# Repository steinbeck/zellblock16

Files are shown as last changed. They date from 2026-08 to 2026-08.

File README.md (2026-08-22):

# Zellblock 16

**Ein selbstgebauter Traktionsakku für den Kumpan 54 ignite.**
16 LiFePO4-Zellen in Reihe, 5,38 kWh, in einem 3D-gedruckten Gehäuse, das
die drei originalen Wechselakkus ersetzt.

> [!CAUTION]
> ### Entwurf — nicht gebaut, nicht getestet, nicht abgenommen
>
> Dieses Repository beschreibt einen **Konstruktionsentwurf**, der als
> Diskussionsgrundlage im [Elektroroller-Forum](https://www.elektroroller-forum.de/)
> gedacht ist. Stand heute gilt ohne Einschränkung:
>
> - **Kein Teil wurde gefertigt.** Sämtliche Maße stammen aus Berechnung und
>   CAD, keines aus einem realen Bauteil in der Hand.
> - **Nichts wurde erprobt** — weder elektrisch noch mechanisch noch thermisch.
>   Kein Strom ist geflossen, keine Zelle wurde verspannt, kein Gehäuse hat je
>   im Akkuschacht gesteckt.
> - **Es gibt keine behördliche Abnahme.** Der Umbau berührt die
>   Betriebserlaubnis und damit den Versicherungsschutz. Eine Prüforganisation
>   war zu keinem Zeitpunkt beteiligt.
>
> Die Zahlen sind sorgfältig hergeleitet und in `grundlagen.md` mit ihrer
> Herkunft belegt — aber hergeleitet ist nicht bewiesen. Wer darauf aufbaut,
> prüft jede einzelne selbst gegen seine eigenen Bauteile und Datenblätter.
>
> **Rückmeldungen sind ausdrücklich erwünscht.** Genau dafür liegt das hier
> öffentlich.

<p align="center">
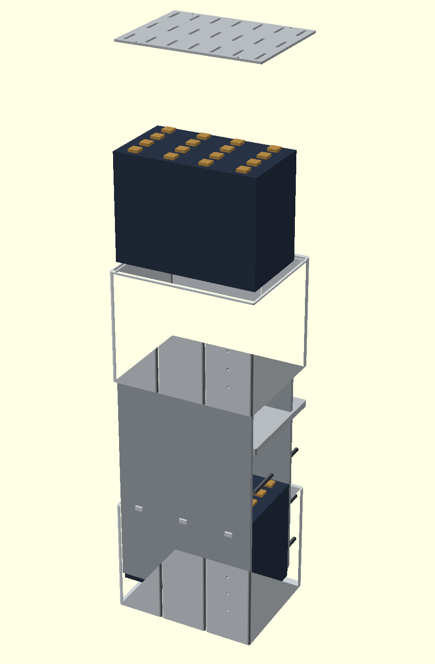
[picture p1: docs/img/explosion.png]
Explosionsdarstellung des Aufbaus
  
</p>

<p align="center">
  <a href="https://steinbeck.github.io/zellblock16/">Projektseite</a> ·
  <a href="https://steinbeck.github.io/zellblock16/blaupause.html">Explosionszeichnung</a> ·
  <a href="https://steinbeck.github.io/zellblock16/verschaltung.html">Verschaltung</a> ·
  <a href="https://steinbeck.github.io/zellblock16/verdrahtung.html">Verdrahtung</a> ·
  <a href="https://steinbeck.github.io/zellblock16/testaufbau.html">Testaufbau</a>
</p>

---

## Worum es geht

Der Kumpan 54 ignite fährt mit bis zu drei Wechselakkus vom Typ Kraftpaket 2.0.
Sie altern, zeigen Fehler, und ihr Batteriemanagement ist auf ein
Flottenmanagement-Backend ausgelegt, das nicht mehr verlässlich erreichbar ist.
Ersatz gibt es — zu **1.400 € pro Stück**.

| | Original, 3 Packs | Zellblock 16 |
|---|---:|---:|
| Preis | 4.200 € | **~1.500 €** |
| Energie | 4,33 kWh | **5,38 kWh** |
| je kWh | 970 € | **282 €** |
| Zyklen | ~1.000 | **> 6.000** |
| Ersatz einer defekten Zelle | ganzer Pack, 1.400 € | eine Zelle, **40 €** |

Am deutlichsten wird es an einem einzelnen Pack: Einer kostet 1.400 € und
liefert 1,44 kWh. Der komplette Eigenbau kostet 1.515 € und liefert 5,38 kWh —
**das 3,7-fache an Energie für 8 % mehr Geld.**

---

## Kenndaten

| | |
|---|---|
| Konfiguration | 16S1P LiFePO4 |
| Zelle | EVE LF105, 105 Ah, 3,2 V |
| Nennspannung | 51,2 V, Ladeschluss 58,4 V |
| Energie | 5,38 kWh |
| Dauerstrom / Spitze | 100 A / 180 A |
| Masse | 43,2 kg |
| Außenmaß | 430 mm hoch; Grundriss wird nach dem Ausmessen neu festgelegt |
| Reichweite, rechnerisch | ~100 km |

---

## Der Aufbau

**Metall trägt, Kunststoff hüllt.** Zwei durchgehende Aluminiumplatten über die
volle Bauhöhe, verbunden durch acht waagerechte Gewindestangen, nehmen die
Zellverspannung auf. Das gedruckte Gehäuse überträgt keine Kräfte — es ist
Hülle, Führung im Schacht und Isolierung gegen den Rahmen.

Die Zellen stehen in **zwei Etagen zu je acht**, angeordnet als zwei Stapel von
vier. Sie quellen über ihre Lebensdauer in Dickenrichtung auf und werden deshalb
mit **3–5 kN je Stapel** vorgespannt; am Lebensende entwickeln sie bis zu 30 kN.

### Drei Zahlen, an denen die Konstruktion hängt

**Die Außenkontur ist keine Erfindung, sondern eine Ableitung.** Sie ist die
Vereinigungsmenge der drei Original-Fachgrundrisse — 90 × 215 mm mit 5 mm
Eckradius, dreimal nebeneinander. Wo zwei Fächer aneinanderstoßen, treffen an
Vorder- und Rückkante zwei Viertelrundungen aufeinander, und dazwischen bleibt
eine Einbuchtung stehen. Genau dort greifen die Führungsrippen des Schachts ein.
**Diese Nuten entstehen von selbst; sie werden nicht konstruiert.** Deshalb passt
die Kontur per Konstruktion, und am Fahrzeug muss nichts gefräst werden.

**Die Höhenbilanz geht mit 425 von 430 mm auf** — aber nur, weil die
Zwischenplatte die 5 mm überstehenden Zellpole samt Busbars und Muttern in
Kanälen aufnimmt, statt sie obendrauf zu addieren. Naiv gerechnet wären es
436 mm, und das Projekt wäre gescheitert.

**In der Breite bleiben 1,7 mm Spiel je Seite** bei einer Drucktoleranz von
±0,4 mm. Deshalb geht dem Vollteil ein Testring voraus.

---

## Dokumente

| Datei | Inhalt |
|---|---|
| [`grundlagen.md`](grundlagen.md) | Faktenbasis. **Jede Zahl trägt eine Herkunftsmarke** — Herstellerdokument, Messung, Berechnung, Recherche oder offener Punkt. |
| [`konstruktion.md`](konstruktion.md) | Konstruktionsspezifikation: Zellen, Anordnung, Skelett, Kräfte, Gehäuse, Elektrik, Montagereihenfolge |
| [`kosten.md`](kosten.md) | Kostenabschätzung, brutto, mit wahrscheinlichem Wert |
| [`einkaufsliste.md`](einkaufsliste.md) | Was für den Funktionstest zu beschaffen ist |
| [`messprotokoll.md`](messprotokoll.md) | Was am Fahrzeug noch zu messen ist |
| [`cad/`](cad/) | Parametrisches OpenSCAD-Modell |
| `blaupause.html`, `verschaltung.html`, `verdrahtung.html`, `testaufbau.html` | Zeichnungen — Explosionsdarstellung, Zellverschaltung, Stromlaufplan, Testaufbau |
| [`spezifikation.md`](spezifikation.md) | Erster Entwurf, **veraltet** — enthält an neun Stellen widerlegte Werte und bleibt nur als Diskussionsverlauf erhalten |

Die Belegmarken in `grundlagen.md` sind der Kern der Dokumentation. Der erste
Entwurf scheiterte daran, dass abgeleitete Forenzahlen und belegte
Herstellerangaben ununterscheidbar nebeneinanderstanden — ein aus einer
ungenauen Anzeige geschätzter Spitzenstrom von 240 A schlug unbemerkt bis in
eine Lieferantenanfrage durch. Der belegte Wert liegt bei 180 A.

---

## CAD

```sh
cd cad
openscad -o testring.stl --export-format binstl testring.scad
openscad -D 'teil="unten"' -o segment_unten.stl --export-format binstl gehaeuse.scad
```

Alle Maße stehen ausschließlich in [`cad/parameter.scad`](cad/parameter.scad).
Ändert sich eines, pflanzt es sich durch alle Teile fort. `assert`-Prüfungen
brechen ab, wenn eine Änderung die Konstruktion unmöglich macht — etwa wenn das
Spiel in der Breite unter die doppelte Drucktoleranz fällt oder die Stirnwand so
dünn wird, dass die Zwickelnut sie durchbricht.

| Teil | Material | Druckzeit |
|---|---:|---:|
| Segment unten | 1,53 kg | ~14,8 h |
| Segment oben | 1,17 kg | ~11,3 h |
| Zwischenplatte | 0,45 kg | ~4,4 h |
| Deckel | 0,20 kg | ~1,9 h |
| **Gesamt** | **3,36 kg** | **~32 h** |

Werkstoff ASA wegen der Sommertemperaturen im Akkuschacht; für den Testring
genügt PETG. Gedruckt auf einem BambuLab H2S — dessen Bauhöhe von 340 mm ist der
Grund für die Zweiteilung des Gehäuses.

---

## Stand

- [x] Faktenbasis aus dem Herstellerdokument
- [x] Zellwahl und Anordnung
- [x] Gehäuse, Zwischenplatte, Deckel als parametrisches Modell
- [x] Testring gedruckt — **passt nicht, Ursache gefunden**
- [ ] **Schacht nach Entfernen der Separationsrippen ausmessen** ← hier steht das Projekt
- [ ] Außenkontur auf Quaderform umstellen, zweiter Testring
- [ ] Zellen und BMS bestellen — siehe [`einkaufsliste.md`](einkaufsliste.md)
- [ ] **Funktionstest außerhalb des Fahrzeugs**, ohne Gehäuse
- [ ] Probefahrt im provisorischen Gehäuse
- [ ] Erst danach: Bodenkontakte ausbauen, Rippen entfernen *(unumkehrbar)*
- [ ] Endgültiges Gehäuse drucken und einbauen
- [ ] Abnahme durch eine Prüforganisation

### Was der Testring ergeben hat

Er passt nicht — und hat damit genau geleistet, wofür er gebaut wurde: **zwei
Stunden Druckzeit statt 32 Stunden und 3,4 kg** beim Vollteil, und der Fehler
wäre sonst erst beim Zusammenbau mit verspanntem Zellstapel aufgefallen.

Die Ursache saß in einer Grundannahme. Ich war davon ausgegangen, dass zwei
Führungsrippen in die **Rundungszwickel** zwischen den Akkus greifen, und hatte
die gesamte Außenkontur darauf aufgebaut. Tatsächlich stehen die Rippen **10 mm**
vor — in einen Zwickel von 5 mm Tiefe passt das nicht. Die Akkus stehen also mit
echtem Spalt nebeneinander, der Schacht ist breiter als angenommen, und die
Nuten sitzen an der falschen Stelle.

**Die Lösung vereinfacht die Konstruktion:** Die beiden Separationsrippen werden
entfernt, die Außenkontur wird ein schlichter Quader statt einer Vereinigung
dreier Fachgrundrisse, und die Stirnwand darf von 8 auf 5 mm dünner werden.

---

## Sicherheit

Es wird mit **58,4 V DC** und Kurzschlussströmen im Kiloampere-Bereich
gearbeitet, an einem Paket von 43 kg. Lithiumzellen können bei Fehlbehandlung in
Brand geraten.

Dieses Repository ist **keine Bauanleitung**, sondern ein unerprobter Entwurf
für ein konkretes Fahrzeug — siehe die Warnung ganz oben. Wer Vergleichbares
vorhat, prüft jede Zahl selbst gegen seine eigenen Bauteile und Datenblätter.

Der Umbau berührt **Betriebserlaubnis und Versicherungsschutz**. Vor der
Nutzung im öffentlichen Straßenverkehr ist eine Prüforganisation einzuschalten.

---

## Dank

An **Raffler** aus dem Elektroroller-Forum für das CAN-Modul, das den
Motorcontroller ohne das originale Batteriemanagement freigibt, und für
Auskünfte, die kein Handbuch enthält: dass alle drei Anschlüsse parallel liegen,
dass jeder 100 A trägt, und dass der Roller über die Datenpins prüft, ob ein
Stromkreis geschlossen ist.

An **JJac**, dessen dokumentierter Umbau an einem 54 Ri zeigte, dass der Weg
überhaupt gangbar ist.

---

## Lizenz

**[CERN Open Hardware Licence Version 2 — Strongly Reciprocal](LICENSE)**
(`CERN-OHL-S-2.0`), Copyright 2026 Christoph Steinbeck.

Die CERN-OHL wurde für genau diesen Fall geschrieben: Sie deckt
**Konstruktionsunterlagen, CAD-Dateien und daraus gefertigte Produkte** ab, wo
Software- und Textlizenzen nur den Quelltext oder den Text erfassen.

Was das praktisch heißt:

- **Nachbauen, ändern, weitergeben ist ausdrücklich erwünscht.**
- Wer den Entwurf verändert und **weitergibt** — als Dateien oder als gebautes
  Gerät —, muss die geänderten Unterlagen unter derselben Lizenz zugänglich
  machen. Verbesserungen fließen so zurück.
- Wer für sich baut und nichts weitergibt, hat keinerlei Pflichten.
- Es gibt **keinerlei Gewährleistung**. Siehe die Warnung am Anfang: Dieser
  Entwurf ist ungebaut und ungeprüft.

Ausgenommen ist das Benutzerhandbuch des Fahrzeugs. Es ist urheberrechtlich
geschütztes Herstellermaterial, gehört nicht zu diesem Repository und wird hier
nur mit Seitenzahlen zitiert.

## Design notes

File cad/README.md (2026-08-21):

# CAD — Zellblock 16

Parametrisches Modell. Alle Maße stehen ausschließlich in
`parameter.scad`; ändert sich eines, pflanzt es sich durch alle Teile
fort. **Nie Maße in die Geometriedateien schreiben.**

## Dateien

| Datei | Inhalt |
|---|---|
| `parameter.scad` | sämtliche Maße, abgeleitete Größen, Plausibilitätsprüfungen |
| `kontur.scad` | Außen- und Innenkontur, Zellraster |
| `testring.scad` | Musterstück T-01 für den Passungstest |
| `gehaeuse.scad` | die beiden Gehäusesegmente |
| `platten.scad` | Zwischenplatte und Deckel |

## Bauen

```sh
openscad -o testring.stl --export-format binstl testring.scad
```

**Die STL-Dateien liegen nicht im Repository.** Sie sind Erzeugnisse aus
den `.scad`-Quellen und würden bei jeder Parameteränderung veralten, ohne
dass es auffiele — und das Projekt ist gerade in Änderung: Der Testring
kann eine Maßkorrektur auslösen, die alle vier Teile betrifft. Einzige
Quelle der Wahrheit sind die `.scad`-Dateien.

Alle Teile auf einmal:

```sh
for t in unten oben; do
  openscad -D "teil=\"$t\"" -o segment_$t.stl --export-format binstl gehaeuse.scad
done
for t in zwischen deckel; do
  openscad -D "teil=\"$t\"" -o $t.stl --export-format binstl platten.scad
done
openscad -o testring.stl --export-format binstl testring.scad
```

Die Echo-Ausgabe listet die abgeleiteten Maße. Die `assert`-Prüfungen in
`parameter.scad` brechen ab, wenn eine Maßänderung die Konstruktion
unmöglich macht — etwa wenn das Spiel in der Breite unter die doppelte
Drucktoleranz fällt oder die Stirnwand die Zwickelnut nicht mehr trägt.

## Zur Außenkontur

Sie ist die **Vereinigungsmenge dreier Originalfach-Grundrisse**, nicht
ein Quader mit angesetzten Nuten. Wo zwei Fächer aneinanderstoßen,
treffen an Vorder- und Rückkante zwei Viertelrundungen aufeinander;
dazwischen bleibt eine linsenförmige Einbuchtung von 2 × 5 mm Breite und
5 mm Tiefe stehen. Das ist die Zwickelnut, in die die Führungsrippe des
Schachts greift. **Sie entsteht von selbst — sie wird nicht
konstruiert.** Damit passt die Kontur per Konstruktion, und am Fahrzeug
muss nichts gefräst werden.

## Testring T-01

Vor der Vollausführung verbindlich. Er prüft in einem Zug:

1. **Passung der Außenkontur** in den Akkuschacht
2. **Eingriff der Führungsrippen** in die vier Zwickelnuten
3. **Innenmaß** gegen zwei echte Zellen — die beiden 2 mm hohen Stege
   innen markieren den Sollplatz des Zellblocks

Dazu Höhenmarken alle 10 mm an der linken Außenwand: Klemmt der Ring,
lässt sich daran ablesen, wie tief er kam.

| | |
|---|---|
| Material | **PETG genügt** — der Ring wird nicht heiß und trägt nichts. ASA erst beim Vollteil. |
| Volumen | ~210 cm³, also rund 225 g |
| Druckzeit | **4–6 h** mit 0,4 mm Düse, 3–4 h mit 0,6 mm |
| Orientierung | stehend, Unterseite auf der Platte |

Die Unterseite bleibt bewusst plan: Nur so lässt sich mit einer
Fühlerlehre feststellen, ob der Ring wirklich auf dem Schachtboden
aufsitzt und nicht irgendwo hängt.

**Warum der Aufwand:** In der Breite bleiben 1,7 mm Spiel je Seite bei
einer erwarteten Drucktoleranz von ±0,4 mm. Ein Fehldruck des Vollteils
kostet 3 kg Material und über 30 Stunden.

## Gehäusesegmente

```sh
openscad -D 'teil="unten"' -o segment_unten.stl --export-format binstl gehaeuse.scad
openscad -D 'teil="oben"'  -o segment_oben.stl  --export-format binstl gehaeuse.scad
```

| | Unterteil | Oberteil |
|---|---:|---:|
| Eingebaute Höhe | 213,5 mm | 207,5 mm |
| Druckhöhe | 221,5 mm¹ | 207,5 mm |
| Material | 1,53 kg | 1,17 kg |
| Durchbrüche | 3 Kabel, 8 Schrauben | 18 Lüftung, 8 Schrauben |

¹ inklusive der überstehenden Zentrierzapfen. Beide liegen unter der
Bauhöhe des H2S von 340 mm; ein `assert` prüft das.

**Zusammen 2,7 kg**, dazu kommen Zwischenplatte und Deckel.

### Wie die Segmente zusammenhalten

**Nicht miteinander** — jedes wird für sich an die **durchgehende hintere
Aluplatte** geschraubt, die mit 400 mm Höhe über die Trennfuge reicht.
Vier Schrauben je Segment durch die 8 mm starke Rückwand in Gewinde im
Aluminium. Die sechs Zentrierzapfen sorgen nur für Flucht beim
Zusammensetzen, sie tragen nichts.

Das ist derselbe Grundsatz wie beim Rest der Konstruktion: Metall trägt,
Kunststoff hüllt.

### Warum es keine Führungsnuten für die Endplatten gibt

Zwischen Seitenwand und Zellblock bleiben nur **2,2 mm**. Eine Nut oder
Führungsrippe bräuchte mehr, und die Seitenwand ist mit 2,5 mm ohnehin am
Limit. Gebraucht werden sie auch nicht: Die hintere Platte liegt flach an
der Rückwand an und ist damit von selbst positioniert; die vordere steht
beim Einbau auf zwei Nasen im Boden und wird anschließend von den
Zugstangen gehalten.

### Warum der Boden nicht verrippt ist

Er liegt vollflächig auf dem Schachtboden auf und kann sich deshalb gar
nicht durchbiegen — er muss die Last nur durchleiten, nicht auf Biegung
aufnehmen. Rippen würden hier bloß die Zellen anheben, statt sie auf dem
Boden stehen zu lassen. Die drei Kabeldurchführungen liegen im hinteren
Bereich beim BMS, wo keine Zellmasse darauf steht.

### Lüftung

216 mm² in den Stirnwänden des Kopfraums. Das ist wenig, aber der
Kopfraum misst nur 12 mm, und thermisch ist es unkritisch: 24 W
Verlustleistung ergeben rund 9 K Übertemperatur, abgeführt über die
Gehäuseoberfläche. Die Schlitze sind vor allem ein Zugeständnis an die
Datenblattwarnung, die Zellen nicht einzukapseln. Die Hauptöffnung trägt
später der Deckel.

## Zwischenplatte und Deckel

```sh
openscad -D 'teil="zwischen"' -o zwischen.stl --export-format binstl platten.scad
openscad -D 'teil="deckel"'   -o deckel.stl   --export-format binstl platten.scad
```

**Die Zwischenplatte ist das Bauteil, an dem die Höhenbilanz hängt.** Sie
sitzt auf den Zellgehäusen der unteren Etage auf und nimmt deren 5 mm
überstehende Pole samt Busbars und Muttern in vier Längskanälen auf,
statt sie obendrauf zu addieren. Ohne diesen Kunstgriff käme der Aufbau
auf 436 statt 425 mm und wäre gescheitert.

Die Kanäle liegen unter den vier Polspalten bei x = 36,4 / 103,4 /
166,7 / 233,7 mm. Dazwischen bleiben 35–39 mm massives Material stehen —
die Platte wird also nicht in Streifen zerlegt. Über den Kanälen tragen
3 mm, ein `assert` prüft das.

Der Deckel trägt die eigentliche Lüftung: **3.570 mm²** gegen 216 mm² in
den Stirnwänden des Kopfraums, wo bei 12 mm Bauhöhe kaum Platz war.

## Materialbedarf und Druckzeit

| Teil | Volumen | Masse |
|---|---:|---:|
| Segment unten | 1.432 cm³ | 1,53 kg |
| Segment oben | 1.093 cm³ | 1,17 kg |
| Zwischenplatte | 423 cm³ | 0,45 kg |
| Deckel | 188 cm³ | 0,20 kg |
| **Gesamt** | **3.136 cm³** | **3,36 kg** |

**Zur Druckzeit.** Der Testring lieferte den Messwert: 210 cm³ in
2 h 10 min im Standardprofil, also **97 cm³/h**.

| Teil | Druckzeit |
|---|---:|
| Segment unten | ~14,8 h |
| Segment oben | ~11,3 h |
| Zwischenplatte | ~4,4 h |
| Deckel | ~1,9 h |
| **Gesamt** | **~32 h** |

Vier Einzeldrucke, der längste knapp fünfzehn Stunden. Die
0,4-mm-Standarddüse genügt; eine 0,6er würde halbieren, wird aber nicht
gebraucht.

> Ein erster Anlauf mit einem hohen Qualitätsprofil brauchte 7 h 45 für
> denselben Ring, was auf 116 h für das Gehäuse hochgerechnet hätte. Für
> die **Maßhaltigkeit** ist das Profil weitgehend gleichgültig: Ob der
> Ring mit 1,7 mm Spiel je Seite passt, hängt an Flusskalibrierung und
> Materialschrumpf, nicht an der Schichthöhe.

## Rückmeldung nach dem Test

Passt der Ring, geht es an die Gehäusesegmente. Klemmt er, bitte melden
**wo** — an den Seitenwänden, an den Zwickeln oder an den Ecken. Danach
wird in `parameter.scad` genau eine Zahl geändert.

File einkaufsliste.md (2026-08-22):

# Einkaufsliste — Funktionstest

**Stand:** 2026-08-22
**Zweck:** Alles für Schritt 1 bis 4 der Vorgehensreihenfolge
(`grundlagen.md` §8.6) — Pack außerhalb des Fahrzeugs aufbauen, anschließen und
am aufgebockten Roller erproben.

> [!CAUTION]
> **Sicherung, Trennschalter und Multimeter sind kein Zubehör.** Ein 16S-Pack
> liefert Kurzschlussströme im Kiloampere-Bereich; ein vergessener Schraubschlüssel
> auf zwei Polen verdampft Metall. Wer ohne diese drei Positionen anfängt, baut
> ohne Bremse.

---

## Bemerkenswert vorab

**Der Testkauf ist fast der gesamte Materialbedarf.** Es fehlen anschließend nur
noch Aluminium-Endplatten (~115 €) und Filament (~110 €). Der Grund: Die Zellen
dominieren die Rechnung, und sie werden vollständig gebraucht — ein reduzierter
Testkauf ist nicht sinnvoll, weil alle sechzehn Zellen aus derselben Charge
stammen müssen (`grundlagen.md` §8.6).

---

## A · Zwingend

| Pos | Artikel | Menge | Preis | Anmerkung |
|---|---|---:|---:|---|
| A1 | **EVE LF105**, 105 Ah, 3,2 V, Grade A | 16 | **640 €** | **eine Bestellung, eine Charge.** 39,98 € brutto je Stück — die 33,60 € im Shop sind der PV-Nullsteuersatz und gelten hier nicht |
| A1b | **CAN-Modul Raffler**, Hardware + **Batteriesimulation** | 1 | **270 CHF** ≈ 285 € | **Ohne Batteriesimulation gibt der Controller nicht frei.** Muss vor dem Testlauf vorliegen. Kontakt: Telegram `t.me/raffler5` |
| A2 | **BMS JK PB2A16S20P**, 16S, 200 A, 2 A aktiver Balancer | 1 | **109 €** | Softwareversion **≥ 6.0** verlangen. Ein RS485-Port bleibt für Rafflers Modul frei |
| A3a | **Busbars kurz**, M6, Lochabstand = **Zellteilung 36,35 mm** | 14 | 42–70 € | 12 gebraucht, 2 Reserve. **Liegen den Zellen nicht bei** |
| A3b | **Verbinder lang oder flexibel**, M6, **Lochabstand 63 mm** | 3 | 15–25 € | 2 gebraucht für den Übergang zwischen den Zellreihen, 1 Reserve |
| A3c | **Kabel für den Etagenübergang**, 35 mm², ~120 mm, beidseitig M6-Kabelschuh | 1 | 8–15 € | verbindet Etage 1 und 2 durch die Zwischenplatte |
| A4 | **Hauptsicherung** ANL/Mega **200 A träge** mit Halter | 1 | 25–35 € | direkt an den Pluspol des Packs |
| A5 | **Batterie-Trennschalter** ≥ 250 A | 1 | 25–45 € | erlaubt spannungsfreies Arbeiten zwischen den Versuchen |
| A6 | **Leistungskabel** 35 mm², schwarz und rot | je 2,5 m | 45–70 € | vom Pack zu den Portleitungen im Schacht |
| A7 | **Kabelschuhe** M6 und M8 für 35 mm² | 10 | 12–20 € | fertig gecrimpte Kabel sind eine Alternative zur Crimpzange |
| A8 | **Multimeter** mit 60-V-DC-Bereich | 1 | 25–60 € | Zellprüfung, Verschaltungskontrolle vor dem ersten Einschalten |
| A9 | **Drehmomentschlüssel** 2–10 Nm | 1 | 30–60 € | **Pole mit 4–6 Nm.** Gewinde sitzen im Aluminium des Zelldeckels |
| | **Summe A** | | **1.261–1.464 €** | |

## B · Provisorische Verspannung

Die Zellen müssen auch beim Test verspannt sein — 3 bis 5 kN je Stapel, sonst
quellen sie auf und nehmen Schaden (`grundlagen.md` §3.3).

| Pos | Artikel | Menge | Preis | Anmerkung |
|---|---|---:|---:|---|
| B1 | Multiplex oder Siebdruckplatte, 18–21 mm | **4** Stück ~300 × 220 mm | 25–40 € | Endplatten, **zwei Blöcke zu acht Zellen** |
| B2 | Gewindestangen M8, verzinkt | **8** × 400 mm | 15–22 € | vier je Block; für den Test genügt Baumarktqualität |
| B3 | Muttern M8 selbstsichernd, Karosseriescheiben | je 16 | 10–15 € | |
| B4 | **Tellerfedern** für M8, ~1.000 N je Stück | 48 | 30–60 € | 6 je Zugstange; halten die Vorspannung und nehmen die Alterungsdehnung auf |
| | **Summe B** | | **80–137 €** | |

> [!IMPORTANT]
> **Die Federn sind kein Zubehör, sondern Voraussetzung.** Die Zellen dehnen
> sich über die Lebensdauer um 0,7–1,5 mm je Stapel. Gegen starre Zugstangen
> ergäbe das rechnerisch über 200 kN — die Zelle nimmt bereits ab 9 kN Schaden.
> Die Federn halten die Vorspannung von 3–5 kN und begrenzen ihren Anstieg auf
> etwa 1,5 kN.
>
> Aufbau je Stange: **drei Paare** — jeweils zwei Federn gleichsinnig
> ineinander für die Kraft, die Paare wechselsinnig gestapelt für den Weg.
>
> **Auch im Testaufbau verwenden.** Die Zellen atmen bei jedem Ladezyklus: schon
> an einer neuen Zelle steigt die Kraft bei starrer Einspannung um bis zu 3 kN.
> Ohne Federn läge man bei 6–7 kN und damit knapp unter der Schadensgrenze — mit
> ihnen bei rund 5 kN. Siehe `testaufbau.html`.

## C · Laden

| Pos | Artikel | Menge | Preis | Anmerkung |
|---|---|---:|---:|---|
| C1 | **Ladegerät CC/CV, 15–20 A, Ausgangsspannung einstellbar 53–58,4 V** | 1 | 170–280 € | siehe Kasten |
| | **Summe C** | | **170–280 €** | Preise streuen stark, hier lohnt ein Vergleich |

> [!IMPORTANT]
> **Die Spannung muss einstellbar sein.** Christoph wohnt auf 800 m; jede Fahrt
> beginnt bergab, und ohne Rekuperation geht die gesamte Lageenergie in die
> Bremsen. Der Pack wird deshalb nur auf **rund 85 %** geladen — einerseits, um
> später Platz für Rekuperation zu lassen, andererseits weil ein LFP-Pack, der
> nicht bis 3,65 V geladen wird, deutlich mehr Zyklen hält.
>
> Ein fest auf 58,4 V eingestelltes Gerät kann das nicht. Für 85 % sind rund
> **54,0 V** einzustellen; die genaue Zuordnung von Spannung zu Ladestand ist bei
> LFP wegen der flachen Kennlinie ohnehin nur ungefähr (`grundlagen.md` §8.2).
>
> **Nicht das Seriengerät verwenden:** dessen 59 V liegen über dem
> LFP-Ladeschluss, und mit 6 A bräuchte es 15 Stunden.

## D · Kleinmaterial

| Pos | Artikel | Preis | Anmerkung |
|---|---|---:|---|
| D1 | Schrumpfschlauch, Isolierband, Kabelbinder | 15–25 € | |
| D2 | Isoliermatte oder Gummimatte als Unterlage | 10–20 € | Pack steht auf dem Werkstattboden |
| D3 | Aderendhülsen und Kabel für die Balancerleitungen | 10–15 € | meist liegt ein Satz beim BMS |
| | **Summe D** | **35–60 €** | |

---

## Gesamt

| Block | von | bis |
|---|---:|---:|
| A Zwingend | 1.261 € | 1.464 € |
| B Verspannung und Federn | 80 € | 137 € |
| C Laden | 170 € | 280 € |
| D Kleinmaterial | 35 € | 60 € |
| **Summe** | **1.546 €** | **1.941 €** |

Davon sind rund **1.030 €** durch konkrete Angebote belegt (Zellen, BMS und
CAN-Modul), der Rest ist geschätzt. Wer Multimeter und Drehmomentschlüssel bereits besitzt, spart
55–120 €.

**Später folgen** nur noch Aluminium-Endplatten (~115 €) und Filament (~110 €),
zusammen rund 225 €.

---

## Was bewusst nicht auf der Liste steht

| Posten | warum später |
|---|---|
| Aluminium-Endplatten | erst für das endgültige Gehäuse; beim Test tun es Holzplatten |
| Filament | die Kontur steht erst nach dem Ausmessen des Schachts fest |
| Vorladewiderstand | nötig vor der ersten Fahrt, nicht für den Aufbau |
| Crimpzange 35 mm² | vermeidbar durch fertig konfektionierte Kabel |
| CAN-Adapter, 30–60 € | kein Teil des Packs — aber **vor dem Umbau** sinnvoll, solange die Originalakkus noch laufen (`grundlagen.md` §8.5) |

---

## Reihenfolge beim Aufbau

1. **Alle 16 Zellen einzeln auf Ruhespannung messen** und notieren. Abweichungen
   über 50 mV zwischen den Zellen vor dem Verschalten klären.
2. Zellen zwischen die Platten setzen, Zugstangen **über Kreuz** anziehen.
3. **Zellen abwechselnd um 180° drehen**, direkt aneinander. Nur so liegen die
   zu verbindenden Pole übereinander (`verschaltung.html`).
4. Verschalten — **Reihenfolge und Polarität zweimal prüfen**, bevor der letzte
   Busbar gesetzt wird. Ein falsch gesetzter Verbinder bedeutet Kurzschluss über
   zwei Zellen. Je Etage sechs kurze Verbinder, **einer lang** für den Übergang
   zwischen den Zellreihen.
5. Balancerleitungen anschließen, dabei **von Zelle 1 aufsteigend**. Am BMS
   erst anstecken, wenn alle Abgriffe sitzen und die Spannungsfolge stimmt.
6. Gesamtspannung messen: bei halb geladenen Zellen **rund 52 V** erwartbar.
7. Erst dann Sicherung einsetzen und Trennschalter schließen.

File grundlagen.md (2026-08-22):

# Grundlagen: Ersatzakku Kumpan 54 ignite

**Stand:** 2026-08-20
**Status:** Verbindliche Arbeitsgrundlage. Ersetzt `spezifikation.md` (veraltet, siehe dort).
**Projektziel:** Ersatz der drei Kraftpaket-2.0-Wechselakkus durch einen fest
verbauten Eigenbau-Pack mit teilweise 3D-gedrucktem Gehäuse.

> **Sicherheitshinweis.** Es wird mit bis zu 59 V DC und Kurzschlussströmen im
> Bereich mehrerer hundert Ampere gearbeitet. Isoliertes Werkzeug verwenden,
> während der Montage stets einen Pol getrennt halten, Zellen gegen Verrutschen
> und gegen Kurzschluss zum Rahmen isolieren. Der Umbau berührt Betriebserlaubnis
> und Versicherungsschutz (Abschnitt 8).

---

## 0. Belegstatus — Legende

Jede Zahl in diesem Dokument trägt eine Herkunftsmarke. Ohne Marke gilt eine
Aussage als unbelegt und darf nicht als Planungsgrundlage dienen.

| Marke | Bedeutung |
|---|---|
| **[HB s]** | Benutzerhandbuch `Materials/Benutzerhandbuch_ignite_54i.pdf`, Dokumentseite s. Herstellerangabe, höchste Belegqualität. |
| **[MESS]** | Von Christoph am Fahrzeug bzw. Akku gemessen. |
| **[BER]** | Aus [HB]- oder [MESS]-Werten berechnet. Rechenweg jeweils angegeben. |
| **[REC]** | Web-Recherche. Marktüblich, aber **nicht produktverbindlich** — vor Bestellung am Datenblatt prüfen. |
| **[ANN]** | Begründete Annahme. Ersetzen, sobald belegbar. |
| **[OFFEN]** | Ungeklärt. Blockiert die jeweils genannte Folgeentscheidung. |

---

## 1. Fahrzeug

| Parameter | Wert | Beleg |
|---|---|---|
| Modell | Kumpan 54 ignite | [HB] |
| Höchstgeschwindigkeit | 100 km/h | [HB 6] |
| Motor | Bürstenloser DC-Radnabenmotor | [HB 68] |
| Maximale Leistung | **7.000 W** | [HB 68] |
| Maximales Drehmoment | 141 Nm | [HB 68] |
| Bordnetz-Spannungswandler | 12 V / 48 V | [HB 69] |
| Leergewicht | **93 kg**, ohne Akkus | [HB 70], [BER] |
| Zulässige Gesamtmasse | **280 kg** | [HB 70] |
| Serienausstattung | 2 Kraftpakete (Christoph hat 3) | [HB 29] |
| Bremsen | Hydraulische Scheibenbremsen, CBS/ABS | [HB 70] |

**Zum Leergewicht.** Das Handbuch nennt 82 kg für iconic und impulse, 93 kg für
ignite, und führt das Akkugewicht mit „9,9 kg pro Akku" **separat** auf. Da
iconic serienmäßig einen und impulse zwei Akkus hat, beide aber mit 82 kg
angegeben sind, können die Akkus nicht enthalten sein. [BER]

> **[OFFEN] — Zulassungsbescheinigung Teil I prüfen.** Verbindlich ist Feld **G**
> (Leermasse) und Feld **F.1** (zulässige Gesamtmasse) in Christophs Papieren,
> nicht das Handbuch. Bei Elektrofahrzeugen wird die Antriebsbatterie in Feld G
> häufig eingerechnet — dann verschiebt sich die Zuladungsrechnung in
> Abschnitt 5. Blockiert: nichts Kritisches, die Reserve ist groß.

---

## 2. Original-Akku „Kraftpaket 2.0"

| Parameter | Wert | Beleg |
|---|---|---|
| Typ | Li-Ionen-Corepack aus Einzelzellen | [HB 27] |
| Nennspannung | **50,6 V** | [HB 27] |
| Kapazität | **28,5 Ah / 1.442 Wh** | [HB 27] |
| Gewicht | **9,9 kg** | [HB 70] |
| Anzahl Steckplätze | 3 | [HB 25] |
| Zulässige Bestückung | 1 bis 3 Stück | [HB 69] |
| Reichweite je Akku (ECE 134/2014) | 36,5 km | [HB 69] |
| Reichweite gesamt, 3 Akkus, real | ~80 km | [HB 69] |

**Beschaffungslage:** Originalpacks sind weiterhin erhältlich, zu **1.400 € pro
Stück** (Stand 2026-08-21). Ein Ersatz aller drei kostet damit 4.200 €. Die
frühere Annahme von ~700 € stammte aus einem Forenbeitrag und ist überholt.

Die Technische-Daten-Seite [HB 69] nennt gerundet „51 V / 29 Ah / 1.470 Wh".
Maßgeblich ist die präzisere Angabe der Akkuseite [HB 27].

**Paritätsziel für den Ersatzpack:** 3 × 1.442 Wh = **4.326 Wh**. [BER]

**Realverbrauch:** 4.326 Wh ÷ 80 km = **54 Wh/km**. [BER]
Nach Prüfnorm: 1.442 Wh ÷ 36,5 km = 39,5 Wh/km. [BER]

---

## 3. Zellkonfiguration

### 3.0 Das Original ist 14S NMC — belegt

Die Konfiguration ist über das Ladegerät eindeutig bestimmt:

| Parameter | Wert | Beleg |
|---|---|---|
| Ladegerät-Typ | PBI48-8, IC-gesteuert, CC-Kennung | [HB 69] |
| Ladegerät-Ausgang | **59 V, 6 A** | [HB 69] |
| Ladezeit je Akku | 4,5 h | [HB 68] |

**Herleitung:** 59 V ÷ 14 = **4,214 V/Zelle** — exakt der Ladeschluss von NMC.
Gegenprobe Nennspannung: 50,6 V ÷ 14 = 3,614 V/Zelle, ebenfalls NMC-typisch. [BER]

**Ausgeschlossene Alternativen** [BER]:
- 13S: 59 ÷ 13 = 4,54 V/Zelle — physikalisch unmöglich.
- 15S: 59 ÷ 15 = 3,93 V/Zelle — kein gängiger Ladeschluss.
- 16S LFP: Für das *Original* ausgeschlossen — 59 V ergäben 3,69 V/Zelle, über
  dem LFP-Ladeschluss. Für den *Ersatzpack* ist es die getroffene Wahl, weil
  dessen Ladegerät ohnehin ersetzt und auf 58,4 V eingestellt wird. Siehe §3.1.

Dieser Befund gilt dem **Originalakku**. Er sagt, welches Spannungsfenster der
Controller ab Werk erwartet — nicht, womit der Ersatzpack gebaut werden muss.
Die Entscheidung darüber steht in §3.1.

### 3.1 Der Ersatzpack wird 16S LFP — Entscheidung

**Gesetzt am 2026-08-21.** Nicht 14S NMC wie das Original, sondern **16 Zellen
LiFePO4 in Reihe**, konkret die EVE LF105.

| Parameter | Wert |
|---|---|
| Konfiguration | **16S1P**, LiFePO4 |
| Zelle | EVE LF105, 105 Ah, 3,2 V |
| Nennspannung | **51,2 V** (16 × 3,2 V) |
| Ladeschluss | **58,4 V** (16 × 3,65 V) |
| Entladeschluss BMS | 44,8 V (16 × 2,8 V) |
| Energie | **5,38 kWh** (+24 % gegenüber Parität) |

**Die Spannungsfenster sind nahezu deckungsgleich** [BER]:

| | 14S NMC (Original) | 16S LFP (Ersatz) |
|---|---|---|
| leer | 42,0 V | 40,0 V |
| nominal | 50,6 V | 51,2 V |
| voll | 58,8 V | 58,4 V |

Beide liegen unter der Obergrenze des Motorcontrollers von 60 V (§3.2).

### Wie die Entscheidung zustande kam

Zunächst war NMC gesetzt, gestützt auf drei Argumente. **Alle drei sind
gefallen:**

| Argument gegen LFP | Warum es nicht mehr trägt |
|---|---|
| „Das Ladegerät liefert 59 V, zu viel für LFP" | Das Serien-Ladegerät wird ohnehin ersetzt — mit 6 A bräuchte es 15 h. Ein neues wird auf 58,4 V eingestellt. |
| „Die flache Entladekurve macht die Ladestandsanzeige unbrauchbar" | Rafflers Modul **interagiert nicht mit dem Akku** und leitet keinen Ladestand ab (§3.2). Es gibt nichts, was falsch anzeigen könnte. |
| „1C Dauerstrom ist zu knapp" | Bei Christophs Fahrprofil bis ~70 km/h liegen 45–65 A an, also 0,4–0,6C. Erst Dauerfahrt bei 100 km/h träfe die Grenze. |

Hinzu kamen zwei Argumente **für** LFP, die vorher nicht bekannt waren:

- **Beschaffbarkeit.** Prismatische NMC-Zellen sind im europäischen Handel
  praktisch nicht erhältlich; der Markt ist LFP-dominiert, weil er vom
  Solarspeicherbau getragen wird. LFP gibt es mit Datenblatt, Gewährleistung und
  in Tagen. Siehe `kosten.md`.
- **Zyklen und Preis.** > 6.000 statt ~800 Zyklen, und 640 € statt 865–1.370 €
  für den Zellsatz.

Dazu kommt die deutlich gutmütigere Thermik — relevant bei einem fest verbauten
Pack, der in der Garage steht.

### Was 16S statt 14S kostet

**Zwei Zellen mehr im Strang.** Raffler hält das für unproblematisch (§3.2), und
das Spannungsfenster bestätigt es. Für die Beschaffung ist es sogar ein Vorteil:
16S-LFP-BMS sind Massenware aus dem Solarspeicherbau.

**Bauform.** Das im LFP-Markt normierte Höhenmaß von ~200 mm passt nicht
beliebig in die 430 mm Bauhöhe. Zwei Etagen à 200,5 mm ergeben 401 mm und lassen
29 mm für Boden, Zwischenplatte und Deckel — das geht auf, aber nur mit dem
Kunstgriff, die überstehenden Pole in der Zwischenplatte zu versenken.
Siehe `konstruktion.md` §8.1.

### 3.2 Auskunft Raffler (CAN-Modul), 2026-08-20

Per Telegram eingeholt. **Belegqualität: Herstelleraussage des Modulentwicklers**,
im Wortlaut vorliegend.

| Frage | Antwort |
|---|---|
| Interagiert das Modul mit dem Akku? | **Nein.** „aktuell kann das Modul einfach vortäuschen, dass ein akku drin ist. mit einem akku selber würde es aber nicht interagieren." |
| Ist 16S LFP nutzbar? | **Ja**, „99 % sicher … problemlos" |
| Spannungsgrenze? | **„der Motorcontroller ist mit max. 60 V der Flaschenhals"** |
| Toleranz nach unten? | „ich bin den roller probeweise auch mit 36 v gefahren. also selbst stärkere abweichungen waren ok" |
| Rekuperation | „ich denke ich bin kurz davor das zu schaffen" — in Arbeit |
| BMS-Anbindung für echte Daten | geplant, aber „nicht in absehbarer zukunft verfügbar" |

**Drei Konsequenzen:**

1. **Die SoC-Frage ist gegenstandslos.** Das Modul leitet keinen Ladestand aus
   der Spannung ab — es sendet erfundene Daten. Das frühere Argument gegen LFP
   („flache Entladekurve macht die Anzeige unbrauchbar") setzte voraus, dass
   überhaupt etwas interpretiert wird. Tut es nicht.
2. **Nach dem Umbau gibt es keine echte Ladestandsanzeige im Roller.** Der SoC
   kommt aus der Bluetooth-App des eigenen BMS. Das gilt chemieunabhängig und ist
   eine bewusst hinzunehmende Folge des Ausstiegs aus dem OEM-Ökosystem.
3. **Neue harte Obergrenze: 60 V am Motorcontroller.** 16S LFP (58,4 V) und
   14S NMC (58,8 V) liegen beide darunter. Das Original-Ladegerät mit 59 V ließe
   nur 1 V Reserve — ein weiterer Grund, es zu ersetzen.

### Anforderung an die BMS-Wahl (Raffler, 2026-08-21)

> „wähle eins welches von der Community schon komplett reverse-engineered wurde.
> also alle Kommunikation bekannt ist, und am besten auch befehle entgegennimmt
> (um die Mosfets am ausgang zu steuern). dies würde es dann in zukunft
> erleichtern es in das Modul einzubinden und dann die richtigen Daten auf dem
> Display anzuzeigen"

Damit ist die BMS-Wahl keine reine Schutzfrage mehr, sondern eine
**Schnittstellenentscheidung**: Sie bestimmt, ob der Roller später wieder einen
echten Ladestand anzeigen kann (§3.2, Punkt 2).

**Erfüllt vom JK-BMS** [REC]:

| Anforderung | Umsetzung |
|---|---|
| Vollständig reverse-engineered | `syssi/esphome-jk-bms` dokumentiert > 40 Modelle |
| Protokoll offengelegt | JK BMS RS485 Modbus V1.0 |
| **Befehle für die MOSFETs** | Schalter für Lade- und Entlade-MOSFET, Balancer, Ladegerät-Modus |
| Schnittstellen | UART-TTL, RS485, BLE; beim JK-PB **zwei RS485-Ports** |

Weitere Implementierungen: `Uksa007/esphome-jk-bms-can` (RS485 und CAN),
`Sleeper85/esphome-yambms` (neuere PB-Modelle).

> **Beim Kauf zu beachten:** Softwareversion **≥ 6.0**, sonst spricht das Gerät
> ein anderes Protokoll. Ein RS485-Port sollte für Rafflers Modul frei bleiben.

### Preise und Funktionsumfang des Moduls (Raffler, 2026-08-22)

Das Modul ist **nicht vorhanden**, sondern zu beschaffen. Der Preis setzt sich
aus Hardware und gewählten Funktionen zusammen:

| Baustein | Preis |
|---|---:|
| Hardware | 70 CHF |
| **Batteriesimulation** | **200 CHF** |
| Uhrzeit auf dem Display | 40 CHF — *in dieser Kombination geschenkt* |
| Originalbatterien auslesen, max. Ladezustand | 40 CHF — nicht nötig |
| Dashboard mit Rollerdaten | 40 CHF — nicht nötig |
| **Benötigt: Hardware + Batteriesimulation** | **270 CHF** |

**Die Batteriesimulation ist der Kern**, nicht ein Zusatz: Sie täuscht dem
Roller die Anwesenheit eines Akkus vor. Ohne sie gibt der Controller nicht frei.
Das Modul muss daher **vor dem Testlauf** vorliegen (§8.5).

### Rekuperation — vorerst nicht verfügbar

> „ich bin sehr zuversichtlich, dass ich das noch rauskriege, allerdings kann ich
> absolut keine Zeitangaben dazu machen. wenn ich dich wäre, würde ich davon
> ausgehen, dass du mittelfristig ohne reku fahren wirst."

**Wichtig: Es ist BMS-unabhängig.** Die Wahl des BMS schränkt die spätere
Nachrüstung nicht ein. Raffler will es selbst, weil er einen eigenen Umbau plant.

Ein möglicher Beitrag von hier aus: **CAN-Mitschnitt einer echten
Rekuperationsfahrt**, solange die Originalakkus noch laufen. Messplan in §8.5.

Praktische Folgen bis dahin: etwas geringere Reichweite im Stadtverkehr — bei
einem Roller typisch 5–15 % — und mehr Verschleiß an den mechanischen Bremsen.
Für die Auslegung des Packs ohne Belang; das BMS muss keinen Ladestrom vom
Motor aufnehmen.

### Schnittstelle zum BMS — noch offen

> „das koppeln mit dem BMS ist in einer ersten phase über Bluetooth gedacht.
> kann aber auch zusätzliche Hardware benötigen, ich weiss es schlicht und
> einfach nicht, am ende soll es ja zuverlässig laufen."

Die Anforderung aus §3.2 bleibt gültig — offengelegte Kommunikation, Befehle für
die Ausgangs-MOSFETs —, **über welche Schnittstelle sie läuft, ist aber offen**.
Das JK-BMS deckt mit Bluetooth, zwei RS485-Ports und CAN alle drei
Möglichkeiten ab und bleibt damit die richtige Wahl.

**Gegenleistung:** Raffler wünscht sich einen Erfahrungsbericht im
Elektroroller-Forum, sobald der Umbau läuft.

Kontakt: Telegram `t.me/raffler5`

---

### 3.3 Mechanische Anforderungen prismatischer Zellen

Aus dem EVE-Datenblatt LF105 (RD-LF105-S01-LF, Rev. C, Mar 2022), Abschnitte
6.2–6.4. Gilt sinngemäß für **alle** prismatischen Zellen, auch NMC. [Datenblatt]

### Verspannung — konstruktionsbestimmend

| Größe | Wert |
|---|---|
| Empfohlene Vorspannung | **3–5 kN** (≈ 300–500 kgf) |
| Maximal normal ertragbar | 7 kN |
| Innere Schäden ab | 9 kN |
| Leckage ab | 15 kN |
| **Ausdehnungskraft am Lebensende (EOL)** | **bis 30 kN** |
| Wirkfläche | 130,30 × 195,50 mm |

Prismatische Zellen quellen über ihre Lebensdauer auf. Wird das nicht durch
Vorspannung aufgenommen, delaminieren die Elektroden und die Kapazität bricht
ein. Die Zelldicke im Datenblatt (36,35 mm) gilt ausdrücklich **nur unter 300 kgf
Verspannung bei 30–40 % SOC** — ungespannt und voll geladen ist die Zelle dicker.

> **Folge für die Konstruktion:** Die Gewindestangen sind nicht bloß
> Gehäuseverbinder, sondern das **tragende Verspannelement**. Sie brauchen steife
> Endplatten, die 300–500 kgf flächig in den Zellstapel einleiten. Eine gedruckte
> Platte leistet das nicht — dort gehören Stahl oder Aluminium hin.

### Nachgiebigkeit ist kein Widerspruch zur Vorspannung

Die Zellen sollen unter Druck stehen — und der Druck darf trotzdem nicht
unkontrolliert steigen. Beides gehört zusammen.

Über die Lebensdauer dehnt sich eine Zelle **irreversibel** aus, durch
SEI-Wachstum und Gasbildung, bei LFP etwa 0,5–1 % der Dicke. Bei vier Zellen im
Stapel sind das **0,7–1,5 mm**. Läuft diese Dehnung gegen eine starre
Einspannung, explodiert die Kraft: [BER]

| | |
|---|---|
| Steifigkeit von 4 × M8 A2, 200 mm lang | ~139.000 N/mm |
| Kraftzuwachs bei 1,5 mm Dehnung | **rechnerisch 208 kN** |
| Innere Schäden laut Datenblatt ab | 9 kN |
| Leckage ab | 15 kN |

So weit kommt es nie — vorher gibt die Endplatte nach oder die Zelle wird
gequetscht. Genau das ist das Problem. **Die 30 kN, die das Datenblatt als
Ausdehnungskraft am Lebensende nennt, sind keine Eigenschaft der Zelle, sondern
die Folge einer zu steifen Einspannung.**

**Gewählt: Tellerfedern auf den Zugstangen.** Sie halten die Vorspannung und
nehmen die Alterungsdehnung auf. Mit rund 1.000 N/mm je Stapel steigt die Kraft
bei 1,5 mm Dehnung nur um 1,5 kN — von 4 auf 5,5 kN, deutlich unter der
9-kN-Grenze. Rund sechs Federn je Stange, Anordnung und Platzierung in
`konstruktion.md` §4.2.

**Verworfen: Schaumlagen zwischen den Zellen.** Sie leisten dasselbe, haben aber
drei Nachteile: Sie vergrößern die Zellteilung von 36,35 auf ~39,35 mm und damit
den nötigen Busbar-Lochabstand, sie isolieren die Zellen thermisch gegeneinander,
und ihre Kennlinie ist schwerer auszulegen als die einer genormten Tellerfeder.

### Wärmeabfuhr

| Richtung | Wärmeleitfähigkeit |
|---|---|
| in der Zellebene (X/Z) | 18–24 W/(m·K) |
| **durch die Zelldicke (Y)** | **1–2 W/(m·K)** |
| Wärmekapazität | 0,9–1,2 kJ/(kg·K) |

Wärme lässt sich über die großen Seitenflächen **kaum** abführen — der Weg dorthin
ist zehn- bis zwanzigfach schlechter leitend. Sie muss über Pole und Zellböden
raus. Das bestimmt, wo im Gehäuse Luft zirkulieren können muss.

Dazu passend eine Warnung aus Abschnitt 7.4 des Datenblatts: *„Do not use plastic
to encapsulate batteries or use plastic for electrical connection."* Gemeint ist
vor allem Vergießen, das die Wärmeabfuhr abschneidet; Kunststoffgehäuse mit
Luftraum sind branchenüblich. Für unseren Wandaufbau heißt das: **Luftspalt und
Wärmepfade einplanen, nicht dicht umschließen.**

### Zulässige Einbaulage — geklärt, stehend

Das EVE-Datenblatt enthält auf 44 Seiten **keine Aussage** zu Ventilorientierung
oder Einbaulage. Herstellerübergreifend gilt jedoch [REC]:

| Lage | Bewertung |
|---|---|
| **Pole oben, stehend** | **empfohlen** — das Sicherheitsventil arbeitet nur in dieser Lage bestimmungsgemäß |
| **Kopfüber** | **verboten** — Elektrolyt sammelt sich im Ventil und setzt es außer Funktion; bei Zellversagen tritt kochende leitfähige Flüssigkeit auf den Klemmenblock aus statt trockenem Gas |
| Auf der Kante liegend | nicht empfohlen, herstellerabhängig; teils Warnung vor verkürzter Lebensdauer |
| Flach auf der großen Fläche | schlechteste der liegenden Varianten |

**Zusätzlich scheitert liegende Montage hier an der Geometrie.** Alle Varianten
wurden gegen 270 × 215 × 430 mm gerechnet [BER]:

| Variante | Pole zeigen nach | Ergebnis |
|---|---|---|
| Auf Kante, Pole nach hinten | Tiefe | 200,5 mm Zelle + 7 mm Busbar/Mutter = 207,5 mm bei 207 mm Innenmaß → passt nicht |
| Auf Kante, Pole zur Seite | Breite | Pole hätten Platz, aber nur 5 × 3 = 15 Plätze; einer fehlt |
| Flach gestapelt, 8 Etagen | Tiefe | 16 Plätze, aber erneut 207,5 mm Polseite bei 207 mm → passt nicht |

Ursache ist strukturell: Die 200,5-mm-Achse trägt die Pole und passt bequem nur
in die 270-mm-Breite. Liegt sie dort, bleiben für die übrigen Achsen zu wenige
Zellplätze; legt man sie in die 215-mm-Tiefe, kollidieren Busbar und Polmutter
mit der Gehäusewand.

> **Entscheidung: stehende Montage, Pole oben.** Sicherheitstechnisch die
> empfohlene Lage, geometrisch die einzig mögliche — und der Lastpfad ist
> sauber, weil die Schwerkraft die Zellen auf die Bodenplatte drückt statt gegen
> eine Seitenwand. **Nicht erneut aufzurollen.**

---

## 4. Ströme

Anders als beim Original trägt in einem 16S1P-Pack **jede einzelne Zelle den
vollen Fahrstrom** — es gibt keine Parallelschaltung, die ihn aufteilt. Beim
Original teilten sich drei Packs den Strom, jeder trug ein Drittel. Damit ist die
Strombelastbarkeit der Zelle das **Auswahlkriterium Nummer eins**, noch vor
Kapazität und Preis.

Gerechnet für **16S LFP** (§3.1):

| Lastfall | Rechnung | Strom | Beleg |
|---|---|---|---|
| Spitze bei vollem Akku | 7.000 W ÷ 58,4 V | 120 A | [BER] |
| Spitze bei Nennspannung | 7.000 W ÷ 51,2 V | 137 A | [BER] |
| Spitze an der BMS-Abschaltung | 7.000 W ÷ 44,8 V | 156 A | [BER] |
| **Spitze bei absolut leerem Akku (Auslegungsfall)** | 7.000 W ÷ 40,0 V | **175 A** | [BER] |
| Dauer, Fahrprofil bis ~70 km/h | 2.300–3.300 W | 45–65 A | [ANN] |
| Dauer bei 100 km/h | ~5.000 W ÷ 51,2 V | ~98 A | [ANN] |

**Auslegungsvorgabe: 100 A Dauer, 180 A Spitze**, letzteres mit Reserve auf die
berechneten 175 A. [BER]

**Zur Zellgrenze:** Die LF105 ist mit 1C = 105 A Dauerstrom angegeben. Beim
realen Fahrprofil liegen 0,4–0,6C an, also reichlich Abstand. Erst Dauerfahrt
bei Höchstgeschwindigkeit träfe die Grenze — ein Fall, der bei diesem Fahrzeug
nicht vorkommt.

Die alte Spezifikation setzte 240 A an, abgeleitet aus einer Forenangabe
(„~14 kW laut BMS-Anzeige"), die deren Autor selbst als ungenau bezeichnete.
Gegen die belegte Maximalleistung von 7.000 W ist dieser Wert um 44 % zu hoch
und hätte ein unnötig teures BMS erzwungen.

---

## 5. Gewicht und Zuladung

| Rechnung | Wert | Beleg |
|---|---|---|
| Leergewicht ohne Akkus | 93,0 kg | [HB 70] |
| mit 3 Original-Kraftpaketen (+29,7 kg) | 122,7 kg | [BER] |
| Zuladung im Originalzustand | **157,3 kg** | [BER] |
| mit Ersatzpack 43,2 kg | 136,2 kg | [BER] |
| **Zuladung mit Ersatzpack** | **143,8 kg** | [BER] |

**Schlussfolgerung:** Das Gewicht ist keine bindende Randbedingung. Bei ~110 kg
tatsächlicher Nutzung (Fahrer 90 kg, Kleidung, Gepäck) bleiben rund 34 kg
Reserve. Die Packmasse stieg im Lauf der Konstruktion von geschätzten 36 auf
43,2 kg, weil das Aluskelett für die Zellverspannung hinzukam (§3.3).

Die 30-kg-Obergrenze der alten Spezifikation war unbegründet — sie war schlicht
das Gewicht der drei Originalakkus.

---

## 6. Bauraum

| Parameter | Wert | Beleg |
|---|---|---|
| Kraftpaket-Außenmaß | **90 × 215 × 410 mm** (B × T × H) | [MESS] |
| Grundriss-Form | **quaderförmig, nicht konisch** | [MESS] |
| Eckradius der Vertikalkanten | **5 mm** | [MESS] |
| Drei Packs nebeneinander | **270 × 215 × 410 mm** | [BER] |
| Bruttovolumen | **23,8 L** | [BER] |
| Einbaulage | Vollständig im Schacht versenkt | [MESS] |
| Schachttiefe, Gegenprobe mit Zollstock | bestätigt 410 mm | [MESS] |
| **Lastpfad** | Akku **steht auf dem Schachtboden auf** | [MESS] |

Die alte Spezifikation nannte 210 × 90 × 340 mm und daraus 19,3 L. Die Höhe war
um 70 mm zu klein und die Achsen waren vertauscht. Beide Fehler zusammen führten
dort zur Fehlentscheidung, prismatische Zellen zu verwerfen.

### Schachtgeometrie

Der Schacht ist **kein Quader mit Trennkammern**, sondern **ein durchgehender
Raum, in den vertikale Führungsrippen hineinragen**. Die Kraftpakete haben
abgerundete Vertikalkanten; wo zwei Packs aneinanderstoßen, klafft an Vorder- und
Rückseite zwischen den beiden Rundungen ein Zwickel auf. Genau dort greifen die
Rippen ein. [MESS]

**Konsequenz für das Gehäuse:** Die Außenkontur ist nicht der Hüllquader, sondern
die **Vereinigungsmenge der drei nebeneinandergestellten Kraftpaket-Konturen** —
ein Körper von 270 × 215 × 410 mm mit vier abgerundeten Außenkanten und
eingeformten Zwickelnuten an den ehemaligen Trennebenen. Diese Kontur passt per
Konstruktion und wird von den Original-Rippen geführt. Bei 5 mm Eckradius kostet
sie nur rund **26 ml, also 0,11 % des Volumens** — vernachlässigbar. [BER]

Rechenweg je Kante: (1 − π/4) × 5² × 410 mm = 2,2 ml; vier Außenkanten plus acht
Kanten, die zu Zwickeln werden, ergeben ~26 ml.

**Der Zwickel ist klein.** Bei 5 mm Radius stoßen an einer Trennebene zwei
Viertelrundungen aufeinander; der freie Querschnitt misst nur etwa 10 × 5 mm. Die
eingreifende Rippe kann also höchstens ~8 × 4 mm stark sein. Für die Führung
eines 9,9-kg-Akkus ist das filigran — beim Messen prüfen, ob die Rippen
tatsächlich nur in diesen Zwickel greifen oder ob sie zusätzlich in eine Nut der
Akkuwand fassen. Siehe `messprotokoll.md`, M10.

Innen bleibt der Raum durchgehend und ungeteilt. Ein Wegfräsen der Rippen ist
**nicht erforderlich** — der Umbau bleibt reversibel.

### Schachtgeometrie — Befund aus dem Testring T-01 (2026-08-21)

**Der erste Testdruck passt nicht.** Damit hat das Musterstück genau geleistet,
wofür es gebaut wurde: Der Fehler kostete zwei Stunden Druckzeit statt 32
Stunden und 3,4 kg beim Vollteil — und wäre sonst erst beim Zusammenbau mit
fertig verspanntem Zellstapel aufgefallen.

**Es gibt zwei Arten von Rippen, nicht eine.** [MESS]

| Art | Anzahl | Vorstand | Bedeutung |
|---|---|---|---|
| **Separationsrippen** | 2 | **10 mm** | trennen die Akkufächer, drücken die Akkus auseinander |
| Versteifungsrippen | 6–7 | 1–2 mm | Spritzgussversteifung der Wanne, **irrelevant** |

Die bisherige Konstruktion setzte voraus, dass die Separationsrippen in die
**Rundungszwickel** zwischen den Akkus greifen. Das ist geometrisch unmöglich:
Bei 5 mm Eckradius ist ein Zwickel 10 mm breit und **5 mm tief** — eine Rippe
mit 10 mm Vorstand passt nicht hinein. Die Akkus stehen deshalb mit einem echten
Spalt nebeneinander, und der Schacht ist breiter als die angenommenen 270 mm.

Eine 10-mm-Nut in einer 8-mm-Wand ist zudem kein Nut, sondern ein Durchbruch.
Die Wand müsste auf 13 mm wachsen und kostete 10 mm Innentiefe — bei einem BMS,
das mit 24 mm Dicke ohnehin knapp sitzt, nicht tragbar.

**Beschluss: Die beiden Separationsrippen werden entfernt.** [Christoph]
Die Versteifungsrippen bleiben und werden mit 2 mm Vorstand berücksichtigt.

Das vereinfacht die Konstruktion an drei Stellen:

| | mit Nuten | ohne |
|---|---:|---:|
| Außenkontur | Vereinigung dreier Fachgrundrisse | **schlichter Quader mit Eckradius** |
| Stirnwand | 8,0 mm (wegen Nuttiefe) | **5,0 mm** |
| frei für BMS | 37,6 mm | **39,6 mm** |
| Spiel in der Breite je Seite | 1,7 mm | **abhängig von der Messung, vermutlich deutlich mehr** |

> **[OFFEN] Zwei Maße nach dem Entfernen:** lichte Weite in der Breite und
> lichte Tiefe bis zur Vorderkante der verbliebenen Versteifungsrippen.
> Blockiert: die Außenkontur.

### Bauhöhe — bestätigt (2026-08-21)

Mit einer auf **425 mm** abgelängten Stahlstange in der vorderen Ecke schließt
die Sitzbank noch. [MESS] Die Konstruktion braucht exakt 425 mm — sie passt
also, aber ohne jede Reserve. Hinten stehen rund **50 mm mehr** zur Verfügung.

Ein gestuftes Gehäuse ist damit **nicht erforderlich**. Stattdessen sind die
**oberen Außenkanten des Deckels zu fasen**: Eine schwenkende Sitzbank
beschreibt einen Kreisbogen, und die obere Außenkante ist der Punkt, der ihm am
nächsten kommt. Bei null Reserve schafft die Fase Freiraum genau dort, ohne in
der Mitte Bauhöhe zu kosten.

### Bodenkontakte — Ausbau beschlossen (2026-08-21)

Am Schachtboden sitzen **drei** Leistungssteckkontakte, je **ca. 20 mm hoch**.
[MESS] Sie greifen in Taschen an der Unterseite des Kraftpakets. Ein Gehäuse mit
planer Unterseite würde auf ihnen aufsitzen und 20 mm Bauhöhe verlieren.

**Entscheidung: Kontakte ausbauen, Direktverkabelung** statt Nutzung der
Originalkontakte.

| | mit Kontakten | ohne |
|---|---|---|
| Nutzbare Bauhöhe | 410 mm | **430 mm** |
| Bodenplatte | drei Aussparungen, an den Traglaststellen geschwächt | **durchgehend eben** |
| Lasteinleitung | um die Taschen herum | **flächig** |
| Kabeldurchführung | neue Durchbrüche nötig | **die freiwerdenden Kontaktöffnungen** |

**Preis:** Nach dem Ausbau lässt sich kein Originalakku mehr einsetzen. Da diese
defekt und nicht mehr beschaffbar sind, vertretbar — aber es ist der Punkt, ab
dem der Umbau nicht mehr rückgängig ist.

**Folge:** Der 12-V-Backup-Pfad (§8.1) wird damit nicht mehr automatisch bedient
und muss separat gelöst werden. Christoph klärt das mit Raffler. **[OFFEN]**

**Lastpfad geklärt:** Der Akku steht mit seiner Unterseite auf dem Schachtboden
auf, er hängt nicht an Auflagen. [MESS] Die Zellmasse wird also über den
Gehäuseboden nach unten abgetragen.

**Die Laststeigerung ist geringer als sie scheint.** 43,2 kg gegenüber 9,9 kg je
Originalakku klingt nach dem Vierfachen, doch die Last verteilt sich auf **alle
drei Fachflächen**:

| | Original, 3 Packs | Ersatzpack |
|---|---|---|
| Masse | 29,7 kg | 43,2 kg |
| Auflagefläche | 58.050 mm² | 58.050 mm² |
| Flächenpressung | 0,0050 N/mm² | **0,0073 N/mm²** — **+45 %** |

Bedingung ist, dass die Bodenplatte eben aufliegt. Nach Ausbau der
Steckkontakte (§6) ist der Schachtboden plan, und der Gehäuseboden liegt
vollflächig auf — er kann sich deshalb gar nicht durchbiegen und braucht keine
Verrippung. [BER]

> **[OFFEN] — noch abzunehmen:** Querschnitt und Höhenerstreckung der
> eingreifenden Rippen; Lage und Höhe der Bodenkontakt-Aussparungen; Anteil des
> Griffs an der Gesamthöhe von 410 mm. Siehe `messprotokoll.md`.
> Blockiert: Innenaufteilung, nicht mehr Außenkontur oder Lastpfad.

---

## 7. Konstruktionsentscheidungen

Getroffen am 2026-08-20, jeweils mit Begründung.

### 7.1 Zellbauform: prismatisch

14 große prismatische Zellen statt ~280 Rundzellen.

| | prismatisch | Rundzellen 21700 |
|---|---|---|
| Zellzahl | 14 | ~280 |
| Verbindung | 14 Schraubverbindungen | ~600 Punktschweißungen |
| Werkzeugbedarf | Schraubenschlüssel | Punktschweißgerät, Nickelband |
| Balancing-Abgriffe | 15 | 15 |

Da der Bauraum mit 23,8 L reichlich ist und das Gewicht nicht bindet, entfällt
der einzige echte Vorteil der Rundzellen — ihre bessere Anpassbarkeit an
verwinkelte Geometrie.

### 7.2 Chemie: LiFePO4, 16S

Siehe §3.1. Das Original ist 14S NMC (§3.0); der Ersatzpack wird 16S LFP, weil
alle drei ursprünglichen Gegenargumente entfallen sind und LFP bei
Beschaffbarkeit, Preis, Zyklenzahl und Thermik überlegen ist.

### 7.3 Gehäuse: Eigenbau, zweiteilig, mit Zugstangen

Das Original-Gehäuse wird **nicht** wiederverwendet (Entscheidung Christoph).

Der Bauraum des BambuLab H2S beträgt 340 × 320 × 340 mm [REC]. Ein Gehäuse von
410 mm Höhe ist damit **nicht am Stück druckbar**. Konstruktionsprinzip daher:

- **zwei übereinanderliegende Segmente**, je ~205 mm hoch
- verbunden durch **durchgehende Gewindestangen** in senkrechten Bohrungen, die
  die gesamte Gehäusehöhe durchdringen
- Zugstangen an den vier Außenecken **plus zwei mittig** in dem Wandmaterial, das
  die Zwickelnuten ohnehin bereitstellen — sonst bliebe die Mitte über 270 mm
  Breite unverspannt

**Nebeneffekt Montage:** Der 43 kg schwere Pack wird nicht als Ganzes in den
410 mm tiefen Schacht gehoben, sondern dort etagenweise aufgebaut: untere Hälfte
(~18 kg) einsetzen, obere aufsetzen, dann Zugstangen durchstecken und verspannen.
Dieselben Stangen verspannen im selben Zug den Zellstapel gegen Vibration.

### 7.4 Kapazitätsziel

**16 × 105 Ah = 5,38 kWh** statt der Parität von 4,33 kWh, also **+24 %
Reichweite** für rund 2 kg Mehrgewicht gegenüber den Originalzellen.
Rechnerische Reichweite: 5.376 Wh ÷ 54 Wh/km ≈ **100 km** real. [BER]

**Zellformat, herstellerbelegt:** EVE LF105, 200,5 × 130,3 × 36,35 mm, 1,98 kg,
Innenwiderstand < 0,35 mΩ, > 6.000 Zyklen. Datenblatt RD-LF105-S01-LF Rev. C.
Anordnung: zwei Etagen à acht Zellen, siehe `konstruktion.md` §3.

---

## 8. Rollerseitige Integration

### 8.1 Anschluss an den Roller — geklärt (Raffler, 2026-08-21)

**Die Handbuchstelle zum vorderen Steckplatz ist irreführend.** [HB 33] schreibt,
das Kraftpaket müsse „mindestens 4 Stunden im **vorderen** Steckplatz" stecken,
um den 12-V-Backup-Akku zu laden. Daraus war hier zunächst eine Sonderfunktion
dieses Platzes abgeleitet worden. Raffler widerspricht eindeutig:

> „die Anschlüsse sind alle Parallel verbunden und gehen über einen
> Sicherungskasten dann alle direkt und zusammen an den Einzigen anschluss am
> Motorcontroller. […] Buchse1 = 12v wird geladen ist mist. der Roller hat 0.00
> möglichkeit herauszufinden auf welcher position dass ein akku sitzt."

Die Handbuchangabe ist eine Vereinfachung für die Bedienungsanleitung. Es gab
ein Modell mit nur einem Port; offenbar sollte eine einzige Anleitung für alle
Varianten reichen. **Der 12-V-Pfad ist damit kein offener Punkt mehr.**

### Topologie

```
Port 1 ┐
Port 2 ┼─ parallel ─→ Sicherungskasten ─→ Motorcontroller (ein Anschluss)
Port 3 ┘
```

| Größe | Wert | Quelle |
|---|---|---|
| Strombelastbarkeit je Port | **100 A** | Raffler |
| Alle drei Ports zusammen | **300 A** | Raffler |
| Benötigt (Spitze) | 180 A | [BER] |

**Ein Port allein trägt unseren Spitzenstrom nicht.** Vorgehen nach Rafflers
Empfehlung: die Leitungen aller drei Ports zusammenführen. Das ist zugleich die
praktischere Lösung — 180 A über eine einzelne Leitung erforderten 35–50 mm²,
die sich im Fahrzeug kaum verlegen lassen; drei vorhandene Leitungen parallel
lösen das mit dem, was schon verbaut ist.

Rafflers Präferenz: *„Wenn ich dich wäre würde ich die Buchsenbox sowieso
komplett entfernen und deine neue batterie direkt über die Kabel verbinden."*
Das deckt sich mit der ohnehin getroffenen Entscheidung, die Steckkontakte
auszubauen (§6).

### Datenpin-Schleife — zwingend

> „Wichtig sind, die datenpins an den Ports, der Roller erkennt, ob der Kreis
> geschlossen ist. machst du die die Buchsenbox auf im roller, so kannst du die
> zwei sich darin befindenden kabel einfach zusammenstecken, und dann ist der
> kreis immer geschlossen."

Der Roller prüft über die Datenpins, ob ein Stromkreis geschlossen ist, und gibt
sonst nicht frei — **unabhängig vom CAN-Modul**. Beim Ausbau der Buchsenbox sind
diese beiden Leitungen dauerhaft zu brücken.

> **Nebenwirkung, bewusst hinzunehmen:** Mit dauerhaft geschlossener Schleife
> kann der Roller nicht mehr erkennen, ob ein Akku fehlt oder unvollständig
> sitzt. Bei einem fest verbauten Pack ist das ohne Belang, es entfällt aber eine
> Schutzfunktion.

### Sicherungskasten

Der fahrzeugseitige Sicherungskasten liegt **hinter** den Ports und bleibt im
Leistungspfad. JJac berichtet von 3 × 60 A parallel [Forum, unbelegt], was zu
drei Ports à 100 A passt. Vor Inbetriebnahme prüfen, ob die dortige Absicherung
zu 180 A Spitzenstrom passt.

### 8.2 Ladestrategie — Teilladung wegen der Wohnlage

**Der Wohnort ist eine Anforderung an das Fahrzeug.** Christoph wohnt auf
**800 m Höhe; jede Fahrt beginnt bergab.** Das macht aus der fehlenden
Rekuperation (§3.2) kein Reichweiten-, sondern ein thermisches Problem:

| | |
|---|---|
| Lageenergie bei 500 m Höhendifferenz, 230 kg | 1,13 MJ = **0,31 kWh** |
| Bei 10 % Gefälle und 40 km/h | ~1.600 W Dauerbremsleistung |
| Über 5 km Abfahrt | **730 kJ** in die Bremsen |
| Entspricht | ~33 Vollbremsungen aus 50 km/h hintereinander |

Rollerbremsen sind klein dimensioniert; Fading auf einer langen Abfahrt ist ein
reales Risiko, kein theoretisches.

**Rekuperation allein löst das nicht.** Ein voller Pack nimmt keine Ladung auf —
das BMS sperrt bei Erreichen des Ladeschlusses, und der Controller bekäme
dieselbe Absage wie heute. Rekuperation hilft ausgerechnet dann nicht, wenn sie
am dringendsten gebraucht wird: bei der ersten Abfahrt nach dem Laden.

**Lösung: nicht voll laden.** Christoph praktiziert das bereits mit den
Originalakkus (85 % über eine externe Ladekonstruktion) und führt es mit dem
neuen Pack fort. [Christoph, 2026-08-22]

| | |
|---|---|
| Reserve bei 85 % Ladung | 0,81 kWh |
| Benötigt für 500 Höhenmeter | ~0,2 kWh nutzbar |
| **Reicht rechnerisch für** | **~1.200 Höhenmeter** |

Der Nebeneffekt ist erwünscht: **Ein LFP-Pack, der nicht bis 3,65 V geladen
wird, hält deutlich mehr Zyklen.**

### Teilladung bei LFP ist unschärfer als bei NMC

Das Datenblatt definiert die Standardladung als CC bis 3,65 V, danach CV bis der
Strom auf 0,05C fällt — erst die CV-Phase bringt die letzten Prozente.

Die **LFP-Kennlinie ist flach**: Zwischen 20 % und 90 % ändert sich die
Zellspannung nur um wenige Zehntelvolt, erst am Ende steigt sie steil an. Eine
Ladeschlussspannung trifft den Ladestand deshalb ungenauer als bei den
NMC-Originalzellen. Richtwerte bei 0,3–0,5C: [REC]

| Ladeschluss je Zelle | Pack | ungefährer SoC |
|---|---:|---:|
| 3,65 V mit voller CV-Phase | 58,4 V | 100 % |
| 3,45 V | 55,2 V | ~95 % |
| 3,40 V | 54,4 V | ~90 % |
| **~3,38 V** | **~54,0 V** | **~85 %** |
| 3,35 V | 53,6 V | ~80 % |

Die Werte schwanken mit Temperatur und Alterung; genauer als „ungefähr" wird es
über die Spannung bei LFP nicht.

> **Folge für die Beschaffung:** Das Ladegerät braucht eine **einstellbare
> Ausgangsspannung**. Ein fest auf 58,4 V eingestelltes Gerät lädt immer voll
> und macht die Teilladung unmöglich. Die Alternative — den Ladeschluss im BMS
> abzusenken — funktioniert, macht das BMS aber vom Schutzorgan zum
> Betriebsmittel und lässt es bei jeder Ladung abschalten.

> **Im Winter bleibt ein Rest.** Unter 0 °C darf LFP nicht geladen werden; das
> BMS sperrt dann unabhängig vom Ladestand. Bei Frost geht es in jedem Fall auf
> den Bremsen ins Tal.

### 8.3 Ladegerät

Das Serien-Ladegerät liefert 59 V / 6 A = 354 W [HB 69]. Für den 5,18-kWh-Pack
ergäbe das **rund 15 Stunden** Ladezeit. [BER]

Empfehlung: Aftermarket-Ladegerät 58,8–59 V CC/CV. Bei 15 A rund 6 h, bei 20 A
rund 4,5 h. [BER]

### 8.4 Fehlercodes des Originalsystems

Zur Einordnung späterer Fehlerbilder [HB 67]: E114 Kurzschluss im Roller /
Softwareproblem im Motorcontroller · E131 Überspannung · E142 Akku leer ·
E155 Akku zu warm zum Laden (> 45 °C) · E166 Akku zu kalt · E2XX schwerer Fehler.
Diese Codes werden im **Display des Akkus** angezeigt, nicht im Roller — sie
entfallen mit dem Umbau.

---

## 8.5 CAN-Mitschnitt zur Rekuperation — Messplan

**Ziel ist nicht, Rafflers Modul nachzubauen.** Die Akkusimulation ist gelöst und
für 270 CHF zu haben; sie zu duplizieren wäre vergeudete Zeit. Offen ist allein
die **Rekuperation** (§3.2), und dafür ist Christoph besser ausgestattet, als es
zunächst scheint.

### Der Ansatz: Differenzexperiment statt Rätselraten

Solange die Originalakkus funktionieren, lässt sich der **echte** CAN-Verkehr
mitschneiden — im Zustand mit und ohne Rekuperation. Der Unterschied zwischen
beiden Mitschnitten ist die gesuchte Information: welche Frames sich ändern,
wenn der Controller Energie zurückspeist.

Zwei Voraussetzungen sind günstig:

- **Drei intakte Originalakkus.** Nach dem Umbau ist diese Möglichkeit
  unwiederbringlich weg (§8.6 Vorgehensreihenfolge).
- **800 m Wohnhöhe.** Eine Bergstrecke mit reproduzierbarem Gefälle liegt vor
  der Haustür.

> **Die offene Frage, die niemand vorab beantworten kann:** Läuft die
> Reku-Freigabe überhaupt über den CAN-Bus? Wenn ja, sind die Aussichten gut.
> Ist sie im Controller verdrahtet oder hängt an einem Signal, das nicht auf dem
> Bus erscheint, hilft kein Mitlesen. Rafflers Einschätzung — „sehr zuversichtlich,
> dass ich das noch rauskriege" — spricht für die erste Möglichkeit.

### Ausrüstung

| Posten | Preis |
|---|---:|
| CAN-Adapter: CANable, USBtin oder Raspberry Pi mit MCP2515 | 30–60 € |
| Software: `can-utils`, SavvyCAN, Wireshark | kostenlos |
| **Summe** | **30–60 €** |

Das Mitlesen ist **passiv** — es wird nur empfangen, nichts gesendet. Kein
Eingriff, kein Risiko, jederzeit abbrechbar. Auf die 120-Ω-Terminierung des
Busses achten und sie nicht verändern.

### Messplan

Jede Fahrt vollständig aufzeichnen, mit Zeitstempel und Notizen zu Tempo,
Gefälle und Gasgriffstellung.

| # | Fahrt | Zweck |
|---|---|---|
| 1 | **Stillstand, Zündung an**, 5 min | Grundrauschen: welche Frames laufen zyklisch, mit welcher Rate |
| 2 | **Ebene, konstant 40 km/h** | Referenz unter Last, ohne Rekuperation |
| 3 | **Bergab mit Rekuperation**, Gas los | **Der Kern.** Welche Frames ändern sich gegenüber 2? |
| 4 | **Bergab, Gas leicht gehalten** | Trennt Schubbetrieb von aktiver Rückspeisung |
| 5 | **Bergauf unter Last** | Gegenprobe: Stromrichtung umgekehrt |
| 6 | **Vollem Akku bergab** | Prüft, ob der Controller Rekuperation bei vollem Pack sperrt — und woran er das erkennt |

**Fahrt 6 ist der eigentliche Erkenntnisgewinn.** Sie klärt, ob die Sperre am
gemeldeten Ladestand hängt. Falls ja, wäre auch erklärt, warum Rekuperation mit
dem simulierten Akku nicht anläuft — und die Lösung könnte darin bestehen, einen
niedrigeren Ladestand zu simulieren. Das ist eine **Hypothese**, keine
Feststellung.

### Auswertung

1. Frames nach CAN-ID gruppieren, zyklische von ereignisgesteuerten trennen.
2. Mitschnitte 2 und 3 byteweise vergleichen. Gesucht sind Bytes, die
   **ausschließlich** bei Rekuperation ihren Wert ändern.
3. Kandidaten gegen Fahrt 4 und 5 prüfen: Ein Stromwert sollte das Vorzeichen
   wechseln, ein Freigabebit nur in Fahrt 3 gesetzt sein.
4. Ergebnisse an Raffler — er kennt Protokoll und Firmware, ihm fehlen die
   Messdaten aus einem Fahrzeug mit intakten Originalakkus.

### Wann das zu tun ist

**Vor dem Umbau.** Nach dem Ausbau der Bodenkontakte gibt es keinen
Originalakku-Betrieb mehr, und damit auch keine Vergleichsmessung. Wenn diese
Daten je erhoben werden sollen, dann in dem Zeitfenster, das jetzt noch offen
ist.

---

## 8.6 Vorgehensreihenfolge — Erprobung vor irreversiblen Eingriffen

**Grundsatz (Christoph, 2026-08-21):** Die Separationsrippen werden erst
entfernt, wenn der Umstieg endgültig ist. Vorher muss der Roller mit den echten
Zellen und dem echten BMS gelaufen sein.

Zwei Eingriffe sind unumkehrbar und schließen die Rückkehr zu den Originalakkus
aus: der **Ausbau der Bodenkontakte** (§6) und das **Entfernen der
Separationsrippen** (§6). Beide dürfen erst erfolgen, wenn feststeht, dass das
neue System funktioniert.

### Der erste Funktionstest braucht kein Gehäuse

Der Pack lässt sich **außerhalb des Fahrzeugs** aufbauen und anschließen:
sechzehn Zellen zwischen zwei Platten mit Gewindestangen verspannt, auf dem
Werkstattboden, mit zwei Leitungen in den Schacht zu den Portkabeln. Damit ist
alles Wesentliche prüfbar, **bevor ein Millimeter Gehäuse gedruckt ist**:

| Prüfung | klärt |
|---|---|
| Roller einschalten | Gibt der Controller frei? Datenpin-Brücke und CAN-Modul korrekt? |
| Rad aufgebockt drehen lassen | Läuft der Motor? Reagiert die Leistungsregelung? |
| Voller Pack bei 58,4 V | **Verträgt der Controller die Spannung?** Nur 1,6 V Abstand zur 60-V-Grenze |
| Last aufnehmen | Verhalten des BMS, Spannungseinbruch, Erwärmung |
| Laden | Ladegerät, Balancing, Abschaltverhalten |

Scheitert etwas, sind die Zellen unbeschädigt und wiederverwendbar, und am
Fahrzeug ist nichts verändert.

**Der Aufbau bildet die spätere Verschaltung eins zu eins ab:** zwei Blöcke zu
acht Zellen, nur nebeneinander statt in zwei Etagen. Damit gilt der
Verschaltungsplan unverändert. Zeichnung: `testaufbau.html` (ZB-16-004).

| | |
|---|---|
| Block, 8 Zellen aufrecht | 291 × 130 mm |
| beide Blöcke | 291 × 261 mm |
| Höhe mit Polen | 200,5 mm |
| Verspannung je Block | 2 Holzplatten 18 mm, 4 Gewindestangen M8 |

> **Auch im Test verspannen — und zwar mit Federn.** Die Zellen atmen bei jedem
> Ladezyklus, nicht erst über Jahre: Laut Datenblatt steigt die Kraft schon an
> einer neuen Zelle um **bis zu 3 kN**, wenn sie starr eingespannt ist. Mit
> 3–4 kN Vorspannung landet man bei 6–7 kN, also unter der Schadensgrenze von
> 9 kN, aber ohne Reserve. Mit Tellerfedern bleibt es bei rund 5 kN. Sie werden
> ohnehin beschafft; sie hier wegzulassen spart nichts.

**Pole zeigen nach oben**, auch im Testaufbau — das Berstventil arbeitet nur in
dieser Lage bestimmungsgemäß (§3.3).

### Reihenfolge

| # | Schritt | umkehrbar? |
|---|---|---|
| 1 | Zellen einzeln auf Ruhespannung prüfen | ja |
| 2 | Pack **außerhalb** verspannen und verschalten, BMS anschließen | ja |
| 3 | Datenpin-Schleife brücken, CAN-Modul einschleifen | ja |
| 4 | **Funktionstest am aufgebockten Roller** | ja |
| 5 | Provisorisches Gehäuse, **Probefahrt** | ja |
| 6 | Bodenkontakte ausbauen | **nein** |
| 7 | Separationsrippen entfernen | **nein** |
| 8 | Schacht ausmessen, Kontur anpassen, Gehäuse drucken | — |
| 9 | Endgültiger Einbau | — |

**Warum Schritt 5 überhaupt nötig ist:** Für eine Probefahrt auf der Straße muss
der Pack gesichert im Fahrzeug sitzen — aufgebockt lässt sich das Fahrverhalten
unter realer Last nicht beurteilen. Das Provisorium muss dafür in den
**unveränderten** Schacht passen, also die 10 mm vorstehenden Separationsrippen
umgehen: rund 205 mm Außentiefe statt 211 mm. Passgenauigkeit ist nebensächlich,
das Teil muss einen Fahrversuch überstehen.

Wer nur aufgebockt testen will, kann Schritt 5 überspringen und nach dem
Ausmessen direkt das endgültige Gehäuse bauen.

### Ein Test mit weniger Zellen lohnt nicht

Elektrisch wäre er möglich — Raffler ist probeweise mit 36 V gefahren, was etwa
11S bis 12S entspräche. Dagegen sprechen drei Punkte [BER]:

- **Kein Kostenvorteil.** Die Zellen werden ohnehin alle gekauft. Und bei 16S1P
  ohne Parallelschaltung müssen **alle sechzehn aus derselben Charge** stammen:
  Die schwächste bestimmt die Packkapazität, ein Ausgleich existiert nicht.
- **Der kritische Punkt bliebe ungeprüft.** Ein 12S-Pack käme auf 43,8 V und
  ließe die Frage offen, ob der Controller die 58,4 V verträgt — genau das
  Risiko, um das es geht.
- **Keine kleinere Bauform.** Ab neun Zellen braucht es ohnehin zwei Etagen; die
  Bauhöhe bliebe bei 425 mm.

---

## 9. Rechtlicher Rahmen

Kein Rechtsrat. Der 54 ignite fährt 100 km/h [HB 6] und ist damit ein Fahrzeug
der Klasse L3e, nicht ein Kleinkraftrad.

- Eingriffe in den Antriebsstrang berühren die Betriebserlaubnis. Die
  **Spannungslage bleibt praktisch unverändert** — 51,2 V nominal und 58,4 V
  Ladeschluss gegenüber 50,6 V und 58,8 V im Original —, obwohl die Zellzahl von
  14 auf 16 steigt und die Chemie wechselt. Die Motorleistung bleibt unberührt.
  Mit einer Prüforganisation ist zu klären, was konkret abnahmepflichtig wird.
- Der Versicherungsschutz im öffentlichen Raum hängt an einer gültigen
  Betriebserlaubnis.
- Reverse Engineering des eigenen Fahrzeugs zu Reparatur- und
  Interoperabilitätszwecken ist in der EU grundsätzlich zulässig. Nachbau der
  CAN-Platine für den Eigengebrauch ist unproblematisch; Weiterverbreitung oder
  Verkauf kann Schutzrechte berühren.

---

## 10. Offene Punkte

Nach blockierender Wirkung sortiert.

| # | Punkt | Blockiert | Abschnitt |
|---|---|---|---|
| 1 | Rippenquerschnitt (M10), Bodenaussparungen (F1), Griffanteil an der Höhe (M7/M8) | Innenaufteilung | 6 |
| 2 | Konkrete Zelle wählen (Maße, Datenblatt, Bezugsquelle) | gesamte Innenaufteilung | 7.4 |
| 3 | Absicherung im fahrzeugseitigen Sicherungskasten gegen 180 A prüfen | Inbetriebnahme | 8.1 |
| 5 | BMS wählen: **16S LFP**, 150 A Dauer, 250 A Spitze, aktiver Balancer | Elektrikplanung | 4 |
| 6 | Ladegerät 58,8–59 V CC/CV, 15–20 A | — | 8.2 |
| 7 | Zulassungsbescheinigung Teil I, Felder F.1 und G | Gewichtsnachweis | 1 |
| 8 | Prüforganisation zu Abnahmepflicht kontaktieren | Zulassung | 9 |
| 9 | Leistungsverkabelung, Hauptsicherung, Vorladewiderstand | Elektrikplanung | — |

---

## 11. Verworfene Optionen

Damit die Diskussion nicht im Kreis läuft.

| Option | Verworfen weil | Datum |
|---|---|---|
| Rundzellen 21700 | ~600 Punktschweißungen ohne Gegenwert, da Bauraum reichlich und Gewicht nicht bindend | 2026-08-20 |
| Original-Gehäuse wiederverwenden | Entscheidung Christoph | 2026-08-20 |
| Trennrippen wegfräsen | Nicht nötig, da Volumen reichlich; erhält Reversibilität und Führungsfunktion | 2026-08-20 |
| 30-kg-Gewichtsobergrenze | Unbegründet; 151 kg Zuladung bleiben auch mit 36-kg-Pack | 2026-08-20 |
| **14S NMC für den Ersatzpack** | Alle drei Gegenargumente zu LFP entfielen (Ladegerät wird ohnehin ersetzt, das CAN-Modul leitet keinen Ladestand ab, Stromreserve reicht beim realen Fahrprofil). Zugleich ist NMC prismatisch in Europa kaum beschaffbar, teurer und hält ~800 statt > 6.000 Zyklen. §3.1 | 2026-08-21 |
| Schaumlagen zwischen den Zellen | Tellerfedern auf den Zugstangen leisten dasselbe, ohne die Zellteilung und damit das Busbar-Maß zu verändern, ohne thermische Isolierung zwischen den Zellen und mit genormter Kennlinie. §3.3 | 2026-08-22 |
| Liegende Zellmontage | Ventil arbeitet nur bei Polen oben bestimmungsgemäß; zusätzlich scheitern alle liegenden Varianten geometrisch (§3.3) | 2026-08-20 |
| Erhalt des OEM-BMS | Es ist die Fehlerquelle: Flottenmanagement-BMS mit GPS/GSM, Backend nicht mehr verfügbar | vorab |

---

## 12. Quellen

1. **Benutzerhandbuch Kumpan 54 ignite**, Kumpan electric, 75 Seiten, erstellt
   2020-10-01. Primärquelle für alle **[HB]**-Angaben; die Zahl dahinter ist die
   Seite im Dokument. **Nicht Teil dieses Repositories** — das Handbuch ist
   urheberrechtlich geschützt und wird hier nur zitiert, nicht weitergegeben.
   Fahrzeughalter erhalten es über Kumpan electric bzw. den Rechtsnachfolger.
2. **`Materials/IMG_6165–6167.jpeg`** — Fotos von Akku und Schacht, 2026-08-20.
3. **Referenzumbau JJac**, Elektroroller-Forum —
   https://www.elektroroller-forum.de/viewtopic.php?p=414287#p414287
   14S-Umbau an einem 54 Ri mit CAN-Modul von „Raffler". Erfahrungsbericht,
   keine belegte Quelle; Zahlenangaben dort vom Autor selbst als ungenau
   bezeichnet.
4. **BambuLab H2S Bauraum** — https://bambulab.com/en-us/h2s
5. **`spezifikation.md`** — **veraltet.** Enthält nachweislich falsche Werte bei
   Bauraum, Kapazität, Spitzenstrom und Gewichtsgrenze. Nur noch als
   Diskussionsverlauf zu lesen, nicht als Datenquelle.

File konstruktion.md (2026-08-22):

# Konstruktionsspezifikation: Ersatzakku Kumpan 54 ignite

**Stand:** 2026-08-21
**Status:** Design abgenommen. Grundlage für den Implementierungsplan.
**Faktenbasis:** `grundlagen.md` — dort stehen Herkunft und Belegqualität aller
Eingangsgrößen. Dieses Dokument leitet daraus die Konstruktion ab.

> **Sicherheitshinweis.** 58,4 V DC, Kurzschlussströme im Kiloampere-Bereich,
> 43 kg bewegte Masse. Isoliertes Werkzeug, während der Montage stets einen Pol
> getrennt halten, Zellen gegen Rahmen isolieren. Der Umbau berührt
> Betriebserlaubnis und Versicherungsschutz.

---

## 1. Kenndaten

| | |
|---|---|
| Konfiguration | **16S1P LFP** |
| Zelle | EVE LF105, 105 Ah, 3,2 V, prismatisch |
| Nennspannung | 51,2 V |
| Ladeschluss | **58,4 V** (16 × 3,65 V) |
| Entladeschluss BMS | 44,8 V (16 × 2,8 V) |
| Energie | **5,38 kWh** (+24 % gegenüber Parität von 4,33 kWh) |
| Dauerstrom Auslegung | 100 A |
| Spitzenstrom Auslegung | **180 A** |
| Rechnerische Reichweite | ~100 km real |
| Gesamtmasse | **~43 kg** |
| Außenmaß | 270 × 215 × 430 mm |
| Verbleibende Zuladung | 144 kg |

**Harte Obergrenze:** Der Motorcontroller verträgt maximal **60 V**
(Auskunft Raffler, `grundlagen.md` §3.2). Der Ladeschluss von 58,4 V lässt
1,6 V Reserve. Das Serien-Ladegerät mit 59 V darf **nicht** verwendet werden.

---

## 2. Zelle

| Parameter | Wert | Quelle |
|---|---|---|
| Höhe über Pole (H1) | 200,50 ± 0,50 mm | Datenblatt |
| Höhe Gehäuse (H2) | 195,50 ± 0,50 mm | Datenblatt |
| Länge (L) | 130,30 ± 0,50 mm | Datenblatt |
| Dicke (T) | 36,35 ± 0,50 mm | Datenblatt, **unter 300 kgf bei 30–40 % SOC** |
| Polabstand | 67 ± 1 mm | Datenblatt |
| Pole | M6 Innengewinde | Händler |
| Masse | 1980 ± 60 g | Datenblatt |
| Innenwiderstand | < 0,35 mΩ | Datenblatt |
| Dauerstrom | 1C = 105 A | Datenblatt |
| Zyklen | > 6.000 | Datenblatt |

**Zur Dicke:** Die 36,35 mm gelten nur unter Verspannung bei mittlerem
Ladezustand. Ungespannt und voll geladen ist die Zelle dicker. Alle
Tiefenmaße dieser Konstruktion setzen die Verspannung nach §4 voraus.

**Strangwiderstand:** 16 × 0,35 mΩ = **5,6 mΩ**.
Spannungseinbruch bei 180 A: **1,0 V**, also 2,0 %. [BER]

---

## 3. Anordnung

### 3.1 Warum sie erzwungen ist

16 Zellen à 200,5 mm Höhe benötigen 75.800 mm² Grundfläche; verfügbar sind
58.050 mm². Also **zwei Etagen à acht Zellen**. Für acht Zellen auf
270 × 215 mm existiert genau eine tragfähige Anordnung: zwei Stapel zu je vier,
nebeneinander.

Alle liegenden Varianten scheiden aus — sicherheitstechnisch (das Berstventil
arbeitet nur bei Polen oben) und geometrisch. Herleitung in `grundlagen.md` §3.3.

### 3.2 Layout einer Etage

```
        ←──────────── 270 mm ────────────→
      ┌──────────────────────────────────┐   ↑
      │╔════════════════════════════════╗│   │  Aluplatte hinten
      │║ ┌─────────────┬─────────────┐  ║│   │
      │║ │  Zelle A1   │  Zelle B1   │  ║│   │
      │║ ├─────────────┼─────────────┤  ║│   │  Zellblock
      │║ │  Zelle A2   │  Zelle B2   │  ║│   │  145,4 mm tief
      │║ ├─────────────┼─────────────┤  ║│   │
      │║ │  Zelle A3   │  Zelle B3   │  ║│   │  215 mm
      │║ ├─────────────┼─────────────┤  ║│   │
      │║ │  Zelle A4   │  Zelle B4   │  ║│   │
      │║ └─────────────┴─────────────┘  ║│   │
      │╚════════════════════════════════╝│   │  Aluplatte vorn
      │  ░░░ BMS, Verkabelung, ~45 mm ░░ │   │
      └──────────────────────────────────┘   ↓
           260,6 mm belegt von 270 mm
```

Die Zellen quellen in **Dickenrichtung** auf, hier also nach hinten. Deshalb
stapeln sie in die Tiefe, wo Raum für Endplatten und Ausdehnung ist. In der
Breite stoßen sie mit den Schmalseiten aneinander; dort findet keine Ausdehnung
statt.

### 3.3 Verschaltung

16S1P: alle Zellen in Reihe, 17 Balancerabgriffe zum BMS.

**Die Zellen werden abwechselnd um 180° gedreht.** Nur so liegen die zu
verbindenden Pole übereinander und die Busbars überbrücken bloß die Zellteilung
von 36,35 mm. Ohne Drehung müsste jeder Verbinder zusätzlich die 67 mm
Polabstand diagonal überwinden.

Innerhalb einer Etage ergibt das eine **Serpentine**: von vorn nach hinten durch
Reihe A, Übergang über die inneren Polspalten, zurück nach vorn durch Reihe B.
Sechs der sieben Busbars sind dadurch kurz und gleich; **nur der Übergang
zwischen den Reihen misst 63,3 mm** und wird in anderer Länge gebraucht.

Pack-Plus und Pack-Minus landen dabei **beide vorn**, mit 63 mm Abstand — dort,
wo das BMS auf der vorderen Aluplatte sitzt.

Zeichnungen: `verschaltung.html` (ZB-16-002) und `verdrahtung.html` (ZB-16-003).

**Anzugsmoment M6-Pole: 4–6 Nm.** Nicht überziehen — die Gewinde sitzen im
Aluminium des Zelldeckels.

---

## 4. Tragendes Skelett

### 4.1 Prinzip

**Metall trägt, Kunststoff hüllt.** Zwei durchgehende Aluminiumplatten über die
volle Bauhöhe, verbunden durch waagerechte Gewindestangen. Das gedruckte
Gehäuse überträgt keine Kräfte.

```
Seitenansicht                Aluplatte 260 × 400 × 8 mm
      ┌─────────────────────────────────────────┐
      │ ▉                                     ▉ │
      │ ▉ ══════ M8 ══════ Zellen Etage 2 ═══ ▉ │
      │ ▉ ══════ M8 ══════                ═══ ▉ │
      │ ▉ ─────────── Zwischenplatte ───────── ▉ │
      │ ▉ ══════ M8 ══════ Zellen Etage 1 ═══ ▉ │
      │ ▉ ══════ M8 ══════                ═══ ▉ │
      │ ▉                                     ▉ │
      └─────────────────────────────────────────┘
         Gehäuse = Hülle, Führung, Isolierung
```

**Warum keine senkrechten Eckstangen:** Die Zellen belegen 260,6 mm der 270 mm
Breite. Nach Abzug der Wände bleiben je Seite unter 2 mm — für eine M8-Stange
werden ringsum etwa 15 mm gebraucht. Es gibt schlicht keine Ecke dafür, und
keine andere Zellanordnung schafft welche.

### 4.2 Verspannungskräfte

| Größe | Wert | Quelle |
|---|---|---|
| Vorspannung je Zellstapel | 3–5 kN | Datenblatt §6.2 |
| **Je Endplattenpaar (2 Stapel)** | **6–10 kN** | [BER] |
| Maximal ertragbar | 7 kN je Stapel | Datenblatt |
| Innere Schäden ab | 9 kN je Stapel | Datenblatt |
| **Ausdehnungskraft am Lebensende** | **bis 30 kN** | Datenblatt §6.3 |

**Zugstangen:** 4 Stück M8 A2-70 je Etage, insgesamt 8.

| | |
|---|---|
| Last je Stange | 1,5–2,5 kN |
| Bruchlast M8 A2-70 | ~25 kN |
| **Sicherheit** | **~10-fach** |
| Anzugsmoment für 2 kN | **3–4 Nm** |

Die Stangen sind unkritisch. **Kritisch sind die Endplatten:** Sie müssen
6–10 kN über 260 × 195 mm verteilen, ohne sich in der Mitte durchzubiegen.
Daher **8 mm Aluminium**; Stahl wäre steifer, wöge aber das Dreifache.

### Nachgiebigkeit: Tellerfedern auf den Zugstangen

Die Vorspannung muss bleiben, ihr Anstieg begrenzt werden. Die Zellen dehnen
sich über die Lebensdauer um 0,7–1,5 mm je Stapel; gegen die Stangensteifigkeit
von ~139.000 N/mm ergäbe das rechnerisch über 200 kN. Herleitung in
`grundlagen.md` §3.3.

| | |
|---|---|
| Federpaket je Stange | ~1.000 N/mm |
| Kraft bei 1,5 mm Dehnung | 4 → **5,5 kN**, unter der 9-kN-Grenze |
| Aufbau je Stange | 3 Paare, gleichsinnig gepaart für Kraft, Paare wechselsinnig für Weg |
| Stück je Stange | ~6 |
| Bauhöhe je Stange | ~6 mm gespannt, 10–15 mm mit Reserve |
| Gesamt bei 8 Stangen | ~48 Federn |

**Alle Federn sitzen an der vorderen Platte.** Hinten liegt die Aluplatte flach
an der Rückwand — dahinter kommt die 5-mm-Gehäusewand und dann der Schacht, dort
ist für eine Mutter kein Platz. Die Anordnung ist damit asymmetrisch, was
funktional ohne Belang ist: Die Kraft im Strang bleibt dieselbe.

**In der Breite gibt es keinen Konflikt mit dem BMS:** Die Zugstangen liegen bei
x = 40 und 230 mm, das BMS mittig bei 85–185 mm. Sie stehen nebeneinander im
Streifen, nicht hintereinander.

### Bearbeitung der Aluplatten

| Platte | Bohrbild |
|---|---|
| **hinten** | **M8-Gewinde** durch die volle Materialstärke, 8 Stück |
| **vorn** | Durchgangsbohrungen ⌀ 9 mm, 8 Stück, plus Gewinde für die BMS-Befestigung |

Acht Millimeter Einschraubtiefe in Aluminium sind bei 2 kN Last unkritisch — die
Bruchlast der Stange liegt bei 25 kN. Gewindeeinsätze sind sinnvoll, wenn der
Pack öfter zerlegt werden soll.

### 4.3 Masse des Skeletts

| Teil | kg |
|---|---|
| 2 Aluplatten 260 × 400 × 8 mm | 4,5 |
| 8 Zugstangen M8, Muttern, Scheiben | 1,5 |
| **Summe** | **6,0** |

---

## 5. Gehäuse

### 5.1 Außenkontur

**Vereinigungsmenge dreier Kraftpaket-Grundrisse:** ein Körper von
270 × 215 × 430 mm mit vier abgerundeten Außenkanten (**r = 5 mm**) und vier
eingeformten Zwickelnuten an den ehemaligen Trennebenen (bei x = 90 und
x = 180 mm, je vorn und hinten).

Die Nuten nehmen die Führungsrippen des Schachts auf. Die Kontur passt per
Konstruktion, weil sie exakt der Hüllform der drei Originalakkus entspricht.
Volumenverlust durch die Rundungen: ~26 ml, also 0,11 %.

**Am Fahrzeug wird nichts gefräst.** Die Rippen bleiben und übernehmen weiterhin
die Seitenführung.

### 5.2 Wandaufbau

| Fläche | Stärke | Begründung |
|---|---|---|
| Seitenwände (links/rechts) | **2,5 mm** | Breite ist der Engpass, siehe §8 |
| Vorder- und Rückwand | **8,0 mm** | siehe Kasten unten — 5,0 mm wären durchbrochen |
| Bodenplatte | 6,0 mm | verrippt, leitet 43 kg flächig ein |
| Zwischenplatte | 12,0 mm | mit Taschen für Pole und Busbars |
| Deckel | 4,0 mm | mit Entlüftungsöffnungen, **obere Außenkanten gefast** |

> **Korrektur 2026-08-21, beim Modellieren gefunden.** Diese Spezifikation
> nannte zunächst 5,0 mm Stirnwand. Das ist unmöglich: Die Zwickelnut zieht die
> Außenkontur an vier Stellen um genau `eckradius` = 5 mm ein. Bei 5,0 mm
> Wandstärke bliebe dort **null** Material — die Wand wäre an den vier
> Rippenaufnahmen durchbrochen. Die Stirnwand muss daher mindestens
> `eckradius + wand_min` betragen; bei 3 mm Mindestwand sind das **8,0 mm**,
> was am Zwickel 3 mm Restwand stehen lässt. Die Bedingung ist in
> `cad/parameter.scad` als `assert` hinterlegt und kann nicht mehr stillschweigend
> unterschritten werden.

**Folge für die Tiefenbilanz:** Der Innenraum schrumpft von 205 auf **199 mm**.
Für BMS und Verkabelung bleiben statt 43,6 nun **37,6 mm** — weiterhin
ausreichend.

### 5.3 Material

**ASA.** Glasübergang ~105 °C gegenüber 80 °C bei PETG, das unter Last bereits
ab 60 °C kriecht. Der Akkuschacht erreicht im Sommer deutlich über 50 °C. Da das
Gehäuse dank des Skeletts keine Kräfte trägt, wäre PETG tolerierbar — der
Aufpreis für ASA ist jedoch gering gegenüber dem Risiko eines Verzugs.

Der BambuLab H2S druckt ASA mit seiner beheizten Kammer prozesssicher.

Bedarf: **3–3,5 kg**, grob 30–50 h Druckzeit.

### 5.4 Segmentierung

Bauraum H2S: 340 × 320 × 340 mm. Ein 430 mm hohes Gehäuse ist nicht am Stück
druckbar.

**Zwei Segmente à 215 mm**, stehend gedruckt mit offener Seite nach oben.
Fügung über **Stufenfalz mit 10 mm Überlappung**, seitlich an die Aluplatten
geschraubt. Die Naht überträgt keine Kräfte — sie muss nur formschlüssig sitzen
und gegen Spritzwasser dicht sein.

### 5.5 Aufnahme des Skeletts

Beide Segmente tragen innen **vertikale Nuten**, in die die Aluplatten von oben
eingeschoben werden. Das fixiert sie während der Montage im Schacht, bevor die
Zellen eingesetzt sind.

---

## 6. Lastpfad

Der Pack steht mit seiner Unterseite auf dem Schachtboden auf. Die drei
Original-Steckkontakte werden **ausgebaut** (`grundlagen.md` §6), wodurch der
Boden plan wird.

| | Original (3 Packs) | Ersatzpack |
|---|---|---|
| Masse | 29,7 kg | 43 kg |
| Auflagefläche | 58.050 mm² | 58.050 mm² |
| Flächenpressung | 0,0050 N/mm² | **0,0073 N/mm²** |
| | | **+45 %** |

Weil die Last auf alle drei Fachflächen verteilt wird, steigt die Pressung nur
um 45 %, nicht um das Vierfache. Dasselbe Verhältnis gilt für Stoßlasten.

**Bedingung:** Die Bodenplatte muss eben aufliegen und darf sich nicht
durchbiegen, sonst konzentriert sich die Last mittig. Daher 6 mm Stärke mit
Kreuzverrippung auf der Oberseite.

Die freiwerdenden Kontaktöffnungen dienen als **Kabeldurchführung** nach unten.

---

## 7. Thermik

| Lastfall | Verlustleistung |
|---|---|
| Fahrprofil Christoph, 65 A | **24 W** |
| 100 A Dauer | 56 W |
| 180 A Spitze | 181 W, sekundenweise |
| Laden mit 20 A | 2 W |

Bei 24 W erwärmen sich 31,7 kg Zellmasse um **2,6 K/h**. Über die
Gehäuseoberfläche von 0,53 m² stellt sich eine Übertemperatur von etwa **9 K**
ein. Bei 30 °C Umgebung also ~39 °C Zelltemperatur, deutlich unter der
65-°C-Grenze des Datenblatts.

**Passive Kühlung genügt. Keine Lüfter.**

Konstruktive Folgen:
- Die Zellen leiten Wärme in ihrer Ebene mit 18–24 W/(m·K), **durch die Dicke
  aber nur mit 1–2 W/(m·K)**. Wärme muss über Pole und Zellböden abgeführt
  werden, nicht über die großen Flächen.
- Deckel mit Entlüftungsöffnungen, Luftspalt zum Schacht.
- Das Datenblatt warnt: *„Do not use plastic to encapsulate batteries."* Nicht
  vergießen, Luftraum belassen.
- Das reale Risiko ist nicht die Eigenerwärmung, sondern Sommerhitze im Schacht.

---

## 8. Maßbilanzen

### 8.1 Höhe — 5 mm Reserve

| | mm | kumuliert |
|---|---|---|
| Bodenplatte | 6,0 | 6,0 |
| Zellkörper Etage 1 (H2) | 195,5 | 201,5 |
| Zwischenplatte mit Polaufnahme | 12,0 | 213,5 |
| Zellkörper Etage 2 (H2) | 195,5 | 409,0 |
| Verschaltungsraum oben | 12,0 | 421,0 |
| Deckel | 4,0 | **425,0** |
| **Reserve auf 430 mm** | | **5,0** |

**Der entscheidende Kunstgriff:** Die Zwischenplatte sitzt auf den Zellgehäusen
(195,5 mm) auf und nimmt die 5 mm überstehenden Pole samt Busbars und Muttern in
**Taschen** auf. Rechnete man die Busbars naiv obendrauf, käme man auf 436 mm
und die Konstruktion wäre gescheitert.

### 8.2 Breite — der Engpass

| | mm |
|---|---|
| Bauraum außen | 270,0 |
| Zellen, 2 × 130,30 | 260,6 |
| Zelltoleranz ungünstig, 2 × 0,5 | +1,0 |
| **verbleibt für zwei Wände und Spiel** | **8,4** |
| davon Wände 2 × 2,5 | 5,0 |
| **Spiel je Seite** | **1,7** |

Die Drucktoleranz des H2S liegt über 270 mm bei etwa ±0,4 mm. Es geht auf, aber
ohne Reserve. **Deshalb ist der Testdruck nach §11.1 verbindlich.**

### 8.3 Tiefe — komfortabel

| | mm |
|---|---|
| Bauraum außen | 215,0 |
| Stirnwände 2 × 8,0 | 16,0 |
| Zellblock 4 × 36,35 | 145,4 |
| Aluplatten 2 × 8,0 | 16,0 |
| **frei für BMS und Verkabelung** | **37,6** |

### 8.4 Masse

| Posten | kg |
|---|---|
| 16 Zellen | 31,7 |
| Aluplatten | 4,5 |
| Zugstangen und Kleineisen | 1,5 |
| Gehäuse ASA | 3,5 |
| BMS, Busbars, Kabel, Isolation | 2,0 |
| **Summe** | **43,2** |

---

## 9. Elektrik

### 9.1 BMS

| Anforderung | Wert |
|---|---|
| Konfiguration | 16S LFP |
| Dauerstrom | ≥ 150 A |
| Kurzzeit | ≥ 250 A |
| Balancing | aktiv bevorzugt |
| Schnittstelle | Bluetooth, für Ladestandsanzeige am Handy |
| Ladeschluss | 3,65 V/Zelle |
| Entladeschluss | 2,8 V/Zelle |
| Temperaturabschaltung | 60 °C |
| Ladesperre unter 0 °C | zwingend |

**Zusätzliche Anforderung — das BMS ist eine Schnittstellenentscheidung.**
Auf Rafflers Rat (`grundlagen.md` §3.2) ist ein Gerät zu wählen, dessen
Kommunikation von der Community **vollständig reverse-engineered** ist und das
**Befehle entgegennimmt**, insbesondere zum Schalten der Ausgangs-MOSFETs. Nur
dann lässt es sich später an sein CAN-Modul anbinden, sodass der Roller wieder
einen echten Ladestand anzeigt statt erfundener Werte.

| Kriterium | Anforderung |
|---|---|
| Protokoll | offengelegt, Community-Implementierung vorhanden |
| Schreibzugriff | Lade- und Entlade-MOSFET schaltbar |
| Schnittstelle | RS485 oder CAN; ein Port bleibt frei für das Modul |
| Softwarestand | JK-BMS: Version ≥ 6.0 |

**Kandidat: JK PB2A16S20P** — 16S, 200 A, 2 A aktiver Balancer, zwei
RS485-Ports, Bluetooth, 109 €. Erfüllt alle Kriterien; die Steuerbefehle für
beide MOSFETs sind in `syssi/esphome-jk-bms` implementiert.

### Einbaulage des BMS — hochkant, nicht liegend

| | Maß |
|---|---|
| JK PB2A16S20P, Hardware V19 | **300 × 100 × 18 mm** |
| Hardware V24 | 300 × 100 × 24 mm |

**Liegend passt es nicht:** 300 mm Länge bei 265 mm Innenbreite. Das wäre beim
Zusammenbau aufgefallen, nicht vorher.

**Hochkant geht es auf**, und zwar besser als liegend:

| Richtung | verfügbar | BMS |
|---|---:|---:|
| Höhe im Streifen | > 400 mm | 300 mm |
| Breite | 265 mm | 100 mm |
| Tiefe des Streifens | 39,6 mm | 24 mm |

**Montage flach auf der vorderen Aluminium-Endplatte.** Sie steht mit
260 × 400 mm ohnehin an dieser Stelle und wirkt als Wärmesenke — bei rund
0,6 mΩ Durchgangswiderstand fallen im BMS an:

| Last | Verlust |
|---|---:|
| Fahrprofil, 65 A | 2,5 W |
| 100 A Dauer | 6 W |
| 180 A Spitze | 19 W |

Im Mittel unkritisch, aber die MOSFETs sitzen auf wenigen Quadratzentimetern
konzentriert. Eine 2,25 kg schwere Aluplatte direkt unter der Platine ist
deutlich besser als ein Bauteil, das frei im Kunststoffgehäuse hängt. Die
Platte braucht dafür Gewindebohrungen; das Bohrbild richtet sich nach dem
gelieferten Gerät.

**Vorteil der 16S-LFP-Konfiguration:** Solche BMS sind Massenware aus dem
Solarspeicherbau — große Auswahl, niedrige Preise, gute Dokumentation.

Das BMS darf im Normalbetrieb nicht begrenzen: 150 A Dauer liegen über der
Zellgrenze von 105 A, sodass das BMS schützt statt zu drosseln.

### 9.2 Kabelführung — von unten nach oben

**Die Richtung ist die umgekehrte der naheliegenden.** Die Anschlussbuchsen des
Rollers liegen **unter** dem Einsatz. Die Portleitungen treten also von unten in
den Pack ein und müssen **durch das Gehäuse nach oben** geführt werden — nicht,
wie zunächst angenommen, aus dem Pack nach unten heraus.

**Der BMS-Streifen ist zugleich der Kabelschacht.** Er ist der einzige über die
volle Höhe durchgehende Freiraum:

| | |
|---|---|
| Streifen | 39,6 mm tief × 265 mm breit × volle Höhe |
| BMS hochkant | 24 mm tief × 100 mm breit |
| **frei für Kabel** | **165 mm Breite** |

| Leitung | Querschnitt | Länge |
|---|---|---|
| Pack + → Sicherung | 35 mm² | ~450 mm |
| Etagenübergang | 35 mm² | ~120 mm |
| Pack − → BMS B− | 35 mm² | ~200 mm |
| BMS P− → Portleitung | 35 mm² | ~150 mm |
| Balancer Etage 1 | 0,5 mm² | 9 Adern |
| Balancer Etage 2 | 0,5 mm² | 8 Adern |
| RS485 zum CAN-Modul | Datenkabel | nach außen |

**Die 450-mm-Leitung ist die unangenehmste.** Bei einer Serpentine über beide
Etagen liegt Pack-Plus oben, die Portleitung unten — diese eine Verbindung
durchquert den gesamten Pack und braucht über die Höhe mehrere
Befestigungspunkte.

> **Zugentlastung ist Pflicht.** Kein Kabel darf am Zellpol ziehen; die Gewinde
> sitzen im Aluminium des Zelldeckels und sind mit 4–6 Nm angezogen. Schellen an
> Bodenplatte und Zwischenplatte.

> **[OFFEN] Durchbruch der Zwischenplatte.** Er muss den Etagenübergang **und**
> neun Balanceradern aufnehmen. Die bisher vorgesehenen 22 mm Durchmesser sind
> dafür knapp; besser zwei getrennte Öffnungen, damit Leistung und Signal nicht
> im selben Loch liegen.

### 9.3 Leistungspfad

| Bauteil | Auslegung |
|---|---|
| Anschluss an den Roller | **Leitungen aller drei Ports zusammenführen** |
| Strombelastbarkeit | 100 A je Port, 300 A zusammen |
| Hauptsicherung | 200 A ANL/Mega, träge |
| Trennschalter | manuell, für Wartung |
| Vorladewiderstand | gegen Einschaltlichtbogen am Controller-Kondensator |
| Kabeldurchführung | durch die freiwerdenden Kontaktöffnungen |

**Alle drei Portleitungen parallel** (`grundlagen.md` §8.1). Ein Port trägt 100 A
und damit unseren Spitzenstrom von 180 A nicht. Zugleich ist es die praktischere
Lösung: 180 A über eine einzelne Leitung erforderten 35–50 mm², die sich im
Fahrzeug kaum verlegen lassen.

**Datenpin-Schleife schließen — zwingend.** Der Roller prüft über die Datenpins
der Ports, ob ein Stromkreis geschlossen ist, und gibt sonst nicht frei; das gilt
unabhängig vom CAN-Modul. Beim Ausbau der Buchsenbox sind die beiden dort
liegenden Leitungen dauerhaft zu brücken. Wird das übersehen, bleibt der Roller
ohne erkennbaren Grund tot.

Der fahrzeugseitige Sicherungskasten liegt hinter den Ports und bleibt im
Leistungspfad. Vor Inbetriebnahme prüfen, ob seine Absicherung zu 180 A passt.

**Vorladung ist nicht optional:** Der Controller enthält Kondensatoren, die beim
Zuschalten einen Stromstoß von mehreren hundert Ampere ziehen. Ohne
Vorladewiderstand verschweißen Schalterkontakte und es entsteht ein Lichtbogen.

### 9.4 Laden

| | |
|---|---|
| Ladeschluss, technisch | 58,4 V (16 × 3,65 V) |
| **Ladeschluss, Betrieb** | **~54,0 V — Teilladung auf ~85 %** |
| Ausgangsspannung | **einstellbar 53–58,4 V** |
| Strom | 15–20 A |
| Ladezeit | ~4,5–6 h |
| Kennlinie | CC/CV |

**Der Pack wird bewusst nicht voll geladen.** Grund ist die Wohnlage auf 800 m:
Jede Fahrt beginnt bergab, und ohne Rekuperation geht die Lageenergie
vollständig in die Bremsen. Die Teilladung hält Platz für spätere Rekuperation
frei und verlängert zugleich die Zellebensdauer. Herleitung samt
Höhenprofil-Rechnung in `grundlagen.md` §8.2.

Das Serien-Ladegerät (59 V, 6 A) ist **ungeeignet**: zu hohe Spannung für LFP
und mit 15 h Ladezeit unbrauchbar.

### 9.5 CAN-Integration

Raffis Modul wird nach JJac-Muster in den CAN-Bus eingeschleift und ersetzt das
OEM-BMS. Das Modul **interagiert nicht mit dem Akku** — es täuscht dessen
Anwesenheit vor. Der Roller braucht vom Pack nur Plus und Minus.

**Folge:** Keine echte Ladestandsanzeige im Roller. Der SoC kommt aus der
BMS-App.

---

## 10. Montagereihenfolge

Der Pack wird **im Schacht aufgebaut**, nicht davor — 43 kg lassen sich nicht als
Block in einen 430 mm tiefen Schacht heben. Jede Einzelkomponente bleibt unter
16 kg, die Zellen wiegen einzeln 2 kg.

1. Original-Steckkontakte ausbauen, Öffnungen als Kabeldurchführung herrichten.
   **Dabei die Datenpin-Leitungen in der Buchsenbox brücken** und die Leitungen
   aller drei Ports zum künftigen Anschlusspunkt zusammenführen
2. Gehäuse-Unterteil einsetzen, Sitz und Rippeneingriff prüfen
3. Bodenplatte einlegen
4. Beide Aluplatten in die Führungsnuten einschieben
5. Zellen Etage 1 einsetzen, Schaumlagen dazwischen
6. Untere Zugstangen einführen, **über Kreuz auf 3–4 Nm anziehen**
7. Zwischenplatte auflegen, Busbars der Etage 1 in die Taschen legen
8. Zellen Etage 2 einsetzen
9. Obere Zugstangen, ebenfalls über Kreuz verspannen
10. Gehäuse-Oberteil aufsetzen, Stufenfalz, an die Aluplatten schrauben
11. Busbars der Etage 2, Balancerkabel, BMS montieren
12. Leistungskabel, Sicherung, Trennschalter, Vorladung
13. Deckel

**Während der gesamten Montage bleibt ein Pol getrennt.**

---

## 11. Verifikation vor der Vollausführung

### 11.1 Testdruck Breitenmuster — verbindlich

Ein 40 mm hoher Ring der echten Außenkontur, etwa 1 h Druckzeit. Prüft in einem
Zug:

- Passung in den Schacht
- Eingriff der Führungsrippen in die Zwickelnuten
- Innenmaß gegen zwei echte Zellen nebeneinander

Erst nach bestandenem Test wird das Vollteil gedruckt. Bei 1,7 mm Spiel je Seite
und ±0,4 mm Drucktoleranz ist dieser Schritt nicht verhandelbar.

### 11.2 Zellprüfung

Alle 16 Zellen vor dem Einbau auf Kapazität und Ruhespannung prüfen. Bei 16
Zellen in Reihe **ohne Parallelschaltung bestimmt die schwächste Zelle die
Packkapazität** — es gibt keinen Ausgleich.

### 11.3 Trockenaufbau

Etage 1 außerhalb des Fahrzeugs aufbauen und verspannen, um Verspannkraft und
Maßhaltigkeit zu prüfen, bevor im Schacht gearbeitet wird.

---

## 12. Offene Punkte

| # | Punkt | Blockiert | Verantwortlich |
|---|---|---|---|
| 1 | Absicherung im fahrzeugseitigen Sicherungskasten gegen 180 A prüfen | Inbetriebnahme | — |
| 2 | Zellbestellung — Preis mit 19 % USt, nicht der Nullsteuersatz für PV | Beschaffung | Christoph |
| 3 | BMS-Auswahl nach §9.1 | Beschaffung | — |
| 4 | Ladegerät 58,4 V CC/CV, 15–20 A | Beschaffung | — |
| 5 | Prüforganisation zur Abnahmepflicht | Zulassung | Christoph |
| 6 | Zulassungsbescheinigung Teil I, Felder F.1 und G | Gewichtsnachweis | Christoph |
| 7 | Rippenquerschnitt für die Zwickelnuten | Detailmaß Gehäuse | Testdruck §11.1 |

---

## 13. Nächster Schritt

Parametrisches OpenSCAD-Modell. Alle Maße dieser Spezifikation werden als
Variablen geführt, sodass eine Korrektur — etwa nach dem Testdruck — sich durch
das gesamte Modell fortpflanzt.

Reihenfolge: Außenkontur und Testring, dann Gehäusesegmente, dann Bodenplatte,
Zwischenplatte und Deckel.

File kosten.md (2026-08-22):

# Kostenabschätzung

**Stand:** 2026-08-21 · **Ersetzt** die NMC-Fassung vom 2026-08-20 vollständig.
**Grundlage:** `konstruktion.md` — 16S1P LFP, EVE LF105, 5,38 kWh.
**Alle Preise brutto**, einschließlich 19 % Umsatzsteuer, als Endkundenpreise
für Privatbezug. Die Spalte „wahrscheinlich" ist der Wert bei vernünftigem
Einkauf — nicht die billigste Quelle, nicht die teuerste.

---

## Was sich gegenüber der ersten Fassung geändert hat

Die erste Abschätzung rechnete mit **14S NMC** und nannte drei Beschaffungswege,
weil prismatische NMC-Zellen in Europa kaum zu bekommen sind. Diese Unsicherheit
ist entfallen:

| | erste Fassung | jetzt |
|---|---|---|
| Chemie | 14S NMC | **16S LFP** |
| Zellbeschaffung | drei Szenarien, 260–1.800 € | **ein Händler, fester Preis** |
| Spanne gesamt | 900–2.950 € | **1.300–1.820 €** |
| Größter Unsicherheitsfaktor | die Zellen | jetzt Ladegerät und Aluzuschnitt |

Zugleich sind zwei Posten hinzugekommen, die es im NMC-Entwurf nicht gab:
**Aluminium-Endplatten und Zugstangen**. Sie ergeben sich aus der
Verspannungsanforderung des Zelldatenblatts (3–5 kN je Stapel), die erst bei der
Auswertung zutage trat.

---

## Belegte Posten

| Posten | Preis | Quelle |
|---|---|---|
| **16 × EVE LF105**, Grade A, 105 Ah | **640 €** | LiFePO Shop GmbH, 39,98 €/Stück |
| **CAN-Modul Raffler**, Hardware + Batteriesimulation | **270 CHF** ≈ 280–290 € | Angabe Raffler, 2026-08-22 |
| **BMS** JK PB2A16S20P, 16S, 200 A, 2 A aktiver Balancer, BT + CAN | **109 €** | powercells.de, inkl. Versand |
| | **~1.030 €** | |

> Der Shop weist die Zelle mit 33,60 € aus — das ist der Nullsteuersatz nach
> § 12 Abs. 3 UStG für Photovoltaikspeicher in Wohngebäuden, der für einen
> Fahrzeugakku nicht gilt. Gerechnet wird durchgehend mit dem Bruttopreis.

Zum BMS: 16S-LFP-BMS sind Massenware aus dem Solarspeicherbau — große Auswahl,
niedriger Preis, gute Dokumentation. Die Wahl fiel nicht nur wegen des Preises
auf das JK-Modell: Raffler verlangt ein Gerät, dessen Kommunikation vollständig
reverse-engineered ist und das Befehle für die Ausgangs-MOSFETs entgegennimmt,
damit sein Modul später echte Daten ans Display liefern kann. Das JK-BMS erfüllt
beides (`grundlagen.md` §3.2).

---

## Geschätzte Posten

### Skelett und Mechanik

| Posten | von | bis | wahrsch. | Anmerkung |
|---|---:|---:|---:|---|
| Aluplatten 2 × 260 × 400 × 8 mm | 80 € | 150 € | **115 €** | ~4,5 kg AlMg3, Zuschnitt inbegriffen |
| Bohrungen für die Zugstangen | 0 € | 60 € | **0 €** | 16 Löcher; in 8 mm Alu selbst machbar |
| Zugstangen M8 A2-70, Muttern, Scheiben | 30 € | 50 € | **40 €** | 2 m Gewindestange, 16 Sicherungsmuttern |
| Busbars M6, 15 Stück | 50 € | 100 € | **75 €** | **nicht im Zelllieferumfang** |
| Schaumlagen | 20 € | 35 € | **28 €** | EPDM 3 mm, ~0,4 m² |
| **Summe** | **180 €** | **395 €** | **258 €** | |

Zu den Busbars: Die Standardschienen aus dem Solarspeicherbau sind meist für
rund 100 A ausgelegt. Bei 180 A Spitzenstrom braucht es kräftigere oder
verzinnte Kupferschienen — daher der höhere Ansatz.

### Gehäuse

| Posten | von | bis | wahrsch. | Anmerkung |
|---|---:|---:|---:|---|
| ASA, 3,5 kg | 75 € | 125 € | **100 €** | Vollteil, zwei Segmente |
| PETG, 0,3 kg | 8 € | 12 € | **10 €** | Testring T-01 |
| **Summe** | **83 €** | **137 €** | **110 €** | |

### Elektrik

| Posten | von | bis | wahrsch. | Anmerkung |
|---|---:|---:|---:|---|
| Ladegerät 58,4 V CC/CV, 15–20 A | 150 € | 250 € | **190 €** | Serienteil ungeeignet: 59 V, nur 6 A |
| Leistungskabel 35 mm², Kabelschuhe | 50 € | 90 € | **70 €** | die Portleitungen selbst sind vorhanden |
| Trennschalter und Vorladewiderstand | 40 € | 100 € | **65 €** | gegen Einschaltlichtbogen |
| Hauptsicherung 200 A ANL mit Halter | 20 € | 35 € | **28 €** | träge |
| Isolation, Schrumpfschlauch, Kleinteile | 30 € | 60 € | **45 €** | |
| **Summe** | **290 €** | **535 €** | **398 €** | |

---

## Gesamt

| Block | von | bis | wahrscheinlich |
|---|---:|---:|---:|
| Zellen, BMS und CAN-Modul *(belegt)* | 1.025 € | 1.035 € | **1.030 €** |
| Skelett und Mechanik | 180 € | 395 € | **258 €** |
| Gehäuse | 83 € | 137 € | **110 €** |
| Elektrik | 290 € | 535 € | **398 €** |
| **Summe brutto** | **1.578 €** | **2.102 €** | **1.796 €** |

**Rechne mit rund 1.800 €** für das fertige Paket. Die Untergrenze setzt
konsequent günstigen Einkauf voraus, die Obergrenze Markenware und
Fremdbohrungen.

**Die Zellen machen nur noch 36 % der Kosten aus.** In der NMC-Fassung
dominierten sie die Rechnung; jetzt dominiert das Drumherum. Weiteres Sparen
lohnt daher nicht am Zellsatz, sondern beim Ladegerät — dort streuen die Preise
am stärksten.

---

## Nicht enthalten

| Posten | Grobwert | Anmerkung |
|---|---|---|
| Prüforganisation, Abnahme | 200–600 € | Umfang ungeklärt, `grundlagen.md` §9 |
| Werkzeug: Crimpzange, Drehmomentschlüssel, Zelltester | 100–300 € | einmalig, teils leihbar |
| Fehldruck des Vollteils | 20–80 € | genau dagegen dient der Testring |

**Projektaufwand insgesamt**, wenn Werkzeug und Abnahme dazukommen und nichts
geliehen wird: **2.100 bis 2.700 €**. Wer Crimpzange und Drehmomentschlüssel im
Haus hat und bei der Abnahme glimpflich davonkommt, liegt näher an 1.700 €.

---

## Einordnung

Die Originalakkus sind weiterhin erhältlich, kosten aber **1.400 € pro Stück**
(Stand 2026-08-21, Angabe Christoph). Für drei Stück also **4.200 €**.

| | Original, 3 Packs | Zellblock 16 |
|---|---:|---:|
| Preis | **4.200 €** | **~1.800 €** |
| Energie | 4,33 kWh | **5,38 kWh** (+24 %) |
| **Preis je kWh** | **970 €** | **282 €** |
| Zyklen | ~1.000 | **> 6.000** |
| Garantie | Herstellerlage unklar | 3 Jahre auf die Zellen |
| Ersatz einer defekten Zelle | ganzer Pack, 1.400 € | eine Zelle, **40 €** |

**Die Ersparnis beträgt rund 2.400 €, also 57 %.** Selbst wenn Werkzeug und
behördliche Abnahme voll hinzugerechnet werden, bleiben es über 1.800 € oder
43 %.

Am deutlichsten wird es an einem einzelnen Pack: **Ein Originalakku kostet
1.400 € und liefert 1,44 kWh. Der komplette Eigenbau kostet rund 1.800 € und
liefert 5,38 kWh** — das 3,7-fache an Energie für 29 % mehr Geld.

Der Preis ist damit das stärkste Argument. Die längere Lebensdauer und die
Reparierbarkeit kommen hinzu: Fällt später eine Zelle aus, kostet der Ersatz 40 €
statt eines kompletten Packs, und die Zelle ist Massenware aus dem
Solarspeicherbau statt eines Ersatzteils, das an einem einzigen Anbieter hängt.

---

## Verbliebene Unsicherheit

Drei Posten tragen den Großteil der 514 € Spannbreite:

| Posten | Spanne | wodurch bestimmt |
|---|---:|---|
| Aluplatten mit Bohrungen | 130 € | ob selbst gebohrt wird |
| Ladegerät | 100 € | Markenware gegen Importgerät |
| Busbars | 50 € | Querschnitt für 180 A |

Alles Übrige ist belegt oder Kleinmaterial ohne Hebelwirkung. Vor der Bestellung
lohnt daher genau ein Preisvergleich: das Ladegerät.

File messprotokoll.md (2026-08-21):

# Messprotokoll — abgeschlossen

> [!NOTE]
> **Alle Punkte sind erledigt.** Dieses Dokument bleibt als Nachweis erhalten,
> woher die Maße in `grundlagen.md` §6 stammen. Neue Messungen sind nicht
> erforderlich — was noch offen war, beantwortet der Testring empirisch.

| Punkt | Ergebnis | erledigt |
|---|---|---|
| Außenmaß Kraftpaket | 90 × 215 × 410 mm | 2026-08-20 |
| Grundriss | quaderförmig, **nicht konisch** | 2026-08-20 |
| Eckradius der Vertikalkanten | **5 mm** | 2026-08-20 |
| Einbaulage | vollständig im Schacht versenkt | 2026-08-20 |
| **M11 Lastpfad** | Akku **steht auf dem Schachtboden auf** | 2026-08-21 |
| **M12 Bodenkontakte** | drei Stück, je ~20 mm hoch — werden **ausgebaut** | 2026-08-21 |
| **M13 Bauhöhe** | **430 mm** nach Ausbau der Kontakte | 2026-08-21 |
| M7/M8 Griffanteil | entfällt: die Bauhöhe ist direkt gesetzt | 2026-08-21 |
| F1 Unterseite | entfällt: die Kontakte werden ausgebaut, der Boden wird plan | 2026-08-21 |
| **M10 Rippenquerschnitt** | wird durch den **Testring T-01** empirisch geprüft | offen → Testring |

---

## Was der Testring beantwortet

Statt weiterer Handmessungen prüft das Musterstück `cad/testring.scad` die
verbliebenen Fragen in einem Zug:

1. **Passung der Außenkontur** in den Akkuschacht
2. **Eingriff der Führungsrippen** in die vier Zwickelnuten — das ist der frühere
   Punkt M10
3. **Innenmaß** gegen zwei echte Zellen, markiert durch zwei Stege im Ring

Klemmt er, ist zu melden **wo**: an den Seitenwänden, an den Zwickeln oder an
den Ecken. Danach wird in `cad/parameter.scad` genau eine Zahl geändert, und
alle vier Teile ziehen nach.

---

## Historischer Stand

Nachfolgend das ursprüngliche Protokoll, wie es vor der Beantwortung aussah.

---

## Bereits geklärt — nicht mehr messen

| Erledigt am 2026-08-20 | Wert |
|---|---|
| Außenmaß Kraftpaket | 90 × 215 × 410 mm |
| Grundriss quaderförmig, **nicht konisch** | keine Einführschrägen nötig |
| Eckradius der Vertikalkanten | **5 mm** |
| Schachttiefe, Gegenprobe mit Zollstock | bestätigt |

Damit ist die **Außenkontur des Gehäuses vollständig bestimmt**: ein Körper von
270 × 215 × 410 mm, entstanden als Vereinigung dreier Rechtecke 90 × 215 mit
5 mm Eckradius. Grundriss abpausen, Konizitätsmessungen und Radienbestimmung
entfallen ersatzlos.

Offen ist jetzt nur noch, was **innen** passiert: wie die Last abgetragen wird
und wo Aussparungen nötig sind.

---

## M13 — Bauhöhe (derzeit der wertvollste Messwert im Projekt)

Entscheidet zwischen zwei Zellwelten. Bitte **zwei getrennte** Maße:

| Nr. | Messstelle | Wert |
|---|---|---|
| **M13a** | Schachtoberkante (umlaufender Kragen) **bis Schachtboden**, Zollstock senkrecht im leeren Steckplatz | ______ mm |
| **M13b** | Schachtoberkante **bis Unterseite der geschlossenen Sitzbank** — der Luftraum darüber | ______ mm |

**Maximale Bauhöhe = M13a + M13b**, abzüglich einiger Millimeter Sicherheit.

> **Warum das so viel entscheidet:** Bei 410 mm scheidet die EVE LF105 aus — zwei
> Etagen ergäben 401 mm und ließen 9 mm für Boden, Zwischenlage und Deckel. Bei
> **rund 430 mm** gehen zwei Etagen stehend auf, mit Polen nach oben, womit auch
> die Frage nach der zulässigen Einbaulage entfällt. Es geht also um eine Zelle
> für 40 € beim deutschen Händler mit drei Jahren Garantie gegen eine
> NMC-Zelle, für die sich bisher kein europäischer Anbieter finden ließ.

> **Wichtige Einschränkung zu M13b:** Ragt das Gehäuse über die Schachtoberkante
> hinaus, wird dieser Teil nicht mehr von den Führungsrippen gehalten. Der
> Überstand muss also entweder schmal genug für den Kragen sein oder sich auf ihm
> abstützen. Bitte beim Messen mit ansehen, wie viel Fläche der Kragen bietet.

---

## M7 / M8 — Wie viel der 410 mm gehört dem Griff?

Am ausgebauten Kraftpaket mit dem Zollstock:

| Nr. | Messstelle | Wert |
|---|---|---|
| **M7** | Korpus allein — Unterkante bis Oberkante, **ohne** Griff | ______ mm |
| **M8** | Gesamt **inklusive** Griff in Ruhestellung | ______ mm |

> Entscheidet, wie viel Bauhöhe unser Gehäuse wirklich ausnutzen darf, und damit
> über die Etagenaufteilung der Zellen. Fällt ein größerer Teil auf den Griff,
> gewinnen wir oben Raum für BMS und Verkabelung — der Bereich muss dann aber
> nicht mehr die volle Gehäusekontur haben.

---

## M11 — Der wichtigste Punkt: Wie trägt der Akku?

Steht das Kraftpaket mit seiner ganzen Unterseite auf dem Schachtboden auf, oder
hängt es an seitlichen Auflagen bzw. am Griff, sodass der Boden frei bleibt?

☐ steht auf dem Boden auf
☐ hängt an Auflagen
☐ Mischform — bitte kurz beschreiben: ________________________________

> **Warum das alles entscheidet:** Ein Originalakku wiegt 9,9 kg, unser Pack rund
> 36 kg — fast das Vierfache, und diese Last hängt an einem Fahrzeug, das über
> Bordsteine fährt. Trägt der Schachtboden, lege ich die Auflagefläche großzügig
> aus und die Zugstangen leiten die Zellmasse nach unten. Hängt der Akku dagegen
> an Auflagen, brauchen wir tragende Struktur an genau diesen Stellen und ein
> anderes Krafteinleitungskonzept. Diese Frage steht vor der ersten Zeile CAD.

---

## M10 — Greifen die Rippen wirklich nur in die Zwickel?

Bei 5 mm Eckradius ist der Zwickel zwischen zwei benachbarten Akkus nur etwa
10 × 5 mm groß. Eine Rippe darin könnte höchstens ~8 × 4 mm stark sein — für die
Führung eines 9,9-kg-Akkus überraschend filigran. Deshalb die Gegenprobe:

**a) Fassen die Rippen zusätzlich in eine Nut in der Akku-Seitenwand?**
Am ausgebauten Akku die beiden 215-mm-Breitseiten mit der Hand abfahren.

☐ glatte Wand, keine Nut  ☐ es gibt eine Nut — Breite/Tiefe: ______ × ______ mm

**b) Über welche Höhe erstrecken sich die Rippen?**
Volle Schachthöhe, oder nur ein Stück oben bzw. unten?

☐ durchgehend  ☐ nur oben  ☐ nur unten  ☐ mehrere kurze Abschnitte

**c) Auch an den Außenwänden?**
Zusätzlich zu den zwei mittleren Rippen — sitzen welche an der linken und rechten
Außenwand des Schachts?

☐ ja, links und rechts  ☐ nur an einer Seite  ☐ nein, nur die zwei mittleren

> Zu (c): Gibt es außen keine, müssen wir die vier Außenkanten des Gehäuses gar
> nicht runden — das vereinfacht den Druck und spart die Rundungsverluste.

---

## M12 — Höhe der Bodenkontaktblöcke

Auf `IMG_6166` stehen zwei Blöcke aus der Bodenplatte hervor. Wie hoch stehen sie
über dem umgebenden Boden? Grobe Schätzung genügt.

______ mm

---
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

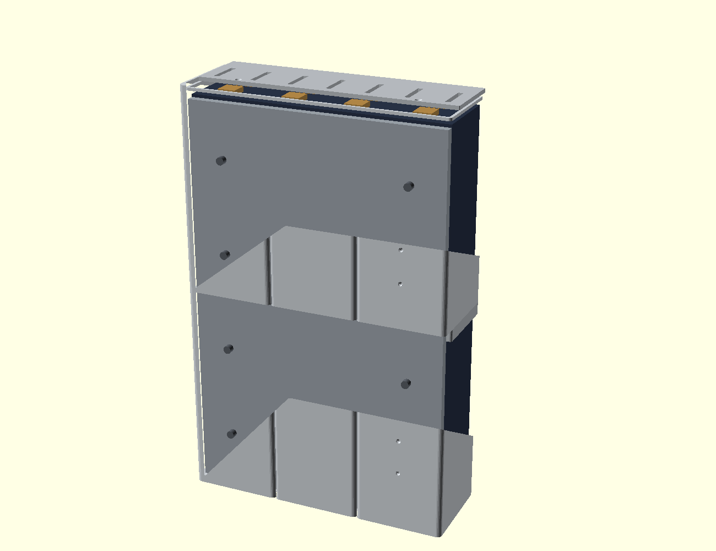
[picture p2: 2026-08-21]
docs/img/schnitt.png

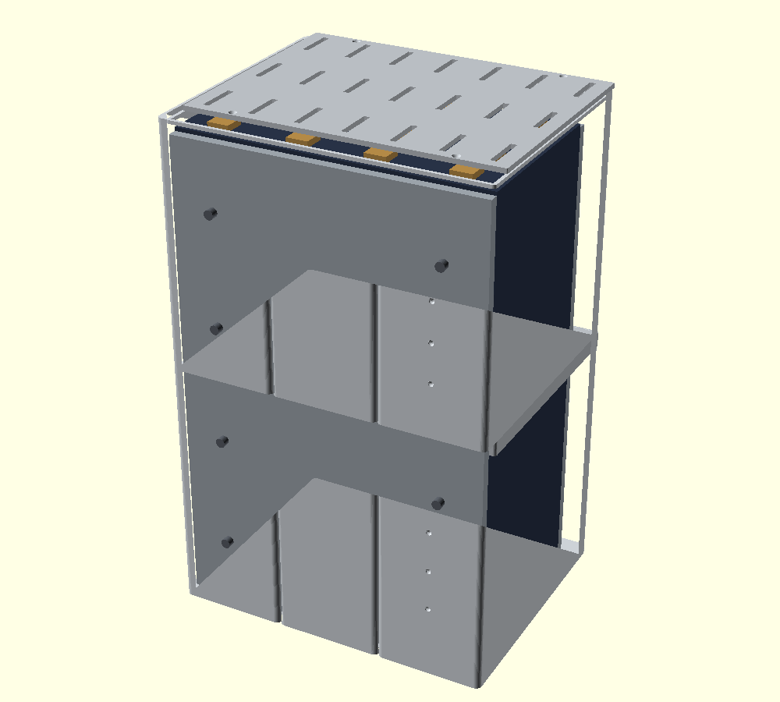
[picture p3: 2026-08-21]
docs/img/zusammen.png

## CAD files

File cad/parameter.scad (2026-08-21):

// SPDX-License-Identifier: CERN-OHL-S-2.0
//
// Copyright 2026 Christoph Steinbeck
//
// This source describes Open Hardware and is licensed under the CERN-OHL-S v2.
// You may redistribute and modify this source and make products using it under
// the terms of the CERN-OHL-S v2 (https://ohwr.org/cern_ohl_s_v2.txt).
// This source is distributed WITHOUT ANY EXPRESS OR IMPLIED WARRANTY, INCLUDING
// OF MERCHANTABILITY, SATISFACTORY QUALITY AND FITNESS FOR A PARTICULAR PURPOSE.
// Please see the CERN-OHL-S v2 for applicable conditions.

// ═══════════════════════════════════════════════════════════════════
//  Zellblock 16 — Parameter
//  Alle Maße in mm. Quelle: ../konstruktion.md
//
//  Diese Datei ist die einzige Stelle, an der Maße stehen. Ändert sich
//  eines — etwa nach dem Testdruck — pflanzt es sich durch alle Teile
//  fort. Nie Maße in die Geometriedateien schreiben.
// ═══════════════════════════════════════════════════════════════════

// ── Bauraum ────────────────────────────────────────────────────────
// Vereinigung dreier Kraftpaket-Grundrisse. konstruktion.md §5.1
bauraum_b      = 270;    // Breite,  3 × 90 mm Fachbreite
bauraum_t      = 215;    // Tiefe
bauraum_h      = 430;    // Höhe, nach Ausbau der Bodenkontakte
fach_b         =  90;    // Breite eines Originalfachs
eckradius      =   5;    // Vertikalkanten des Originalakkus. Erzeugt
                         // zugleich die Zwickelnuten für die Rippen.

// ── Zelle: EVE LF105 ───────────────────────────────────────────────
// Herstellerdatenblatt RD-LF105-S01-LF Rev. C. konstruktion.md §2
zelle_l        = 130.30; // Länge
zelle_t        =  36.35; // Dicke, unter 300 kgf bei 30–40 % SOC
zelle_h1       = 200.50; // Höhe über Pole
zelle_h2       = 195.50; // Höhe Gehäuse
zelle_tol      =   0.50; // Fertigungstoleranz je Maß
zelle_polabst  =  67.00; // Polabstand

zellen_je_reihe = 2;     // nebeneinander in der Breite
zellen_je_stapel= 4;     // hintereinander in der Tiefe
etagen          = 2;

// ── Wandstärken ────────────────────────────────────────────────────
// ACHTUNG Stirnwand: Die Zwickelnut zieht die Außenkontur um
// eckradius (5 mm) ein. Die Stirnwand muss deshalb mindestens
// eckradius + wand_min stark sein, sonst ist sie am Zwickel
// durchbrochen. konstruktion.md nannte 5,0 mm — das war zu wenig.
wand_min       = 3.0;                       // dünnste tragbare Wand
wand_seite     = 2.5;                       // links/rechts, Engpass Breite
wand_stirn     = eckradius + wand_min;      // vorn/hinten = 8,0 mm
boden_dicke    = 6.0;
zwischenplatte = 12.0;
deckel_dicke   = 4.0;

// ── Skelett ────────────────────────────────────────────────────────
endplatte_dicke = 8.0;   // Aluminium
endplatte_b     = 260.0;
endplatte_h     = 400.0;
zugstange_d     = 8.0;   // M8

// ── Fügung und Befestigung ─────────────────────────────────────────
zapfen_b       = 4.0;    // Zentrierzapfen an der Trennfuge, Querschnitt
zapfen_l       = 14.0;
zapfen_h       = 8.0;
zapfen_spiel   = 0.25;   // je Seite, für die Drucktoleranz

schraube_d     = 4.5;    // Durchgang M4 in die Aluplatte
schraube_kopf  = 8.5;    // Senkung
schrauben_je_segment = 4;

auflage_b      = 3.0;    // Deckelauflagestufe im Oberteil
lueftung_b     = 4.0;    // Entlüftungsschlitze im Oberteil
lueftung_n     = 9;

kabel_d        = 26.0;   // Durchführungen im Boden, an den Fachmitten,
                         // wo die Originalkontakte saßen

// ── Fertigung ──────────────────────────────────────────────────────
druck_tol      = 0.4;    // erwartete Maßabweichung H2S über 270 mm
segment_h      = 215;    // Gehäusesegment, 2 × = bauraum_h

// ── Auflösung ──────────────────────────────────────────────────────
$fn = 48;

// ═══════════════════════════════════════════════════════════════════
//  Abgeleitete Größen — nicht von Hand ändern
// ═══════════════════════════════════════════════════════════════════
innen_b     = bauraum_b - 2 * wand_seite;              // 265,0
innen_t     = bauraum_t - 2 * wand_stirn;              // 199,0

zellblock_b = zellen_je_reihe  * zelle_l;              // 260,6
zellblock_t = zellen_je_stapel * zelle_t;              // 145,4

spiel_b     = innen_b - zellblock_b - 2 * zelle_tol;   // 3,4 → 1,7 je Seite
rest_t      = innen_t - zellblock_t - 2 * endplatte_dicke; // für BMS

// Höhenbilanz. konstruktion.md §8.1
kopfraum     = 12;   // Verschaltungsraum über der oberen Etage
hoehe_belegt = boden_dicke + zelle_h2 + zwischenplatte
             + zelle_h2 + kopfraum + deckel_dicke;
hoehe_reserve = bauraum_h - hoehe_belegt;

// Trennfuge der beiden Gehäusesegmente. Sie liegt auf der Oberkante der
// Zwischenplatte — dort ist ohnehin eine steife Ebene, und keine Zelle
// wird geschnitten.
fuge_z       = boden_dicke + zelle_h2 + zwischenplatte;   // 213,5
seg_u_h      = fuge_z;                                     // Unterteil
seg_o_h      = hoehe_belegt - deckel_dicke - fuge_z;       // Oberteil

// Lage der Endplatten in der Tiefe
platte_hinten_y = wand_stirn;
platte_vorn_y   = wand_stirn + endplatte_dicke + zellblock_t;

echo(str("── Zellblock 16 ──────────────────────────"));
echo(str("Innenmaß          ", innen_b, " × ", innen_t, " mm"));
echo(str("Zellblock         ", zellblock_b, " × ", zellblock_t, " mm"));
echo(str("Spiel Breite      ", spiel_b, " mm gesamt, ",
         spiel_b/2, " je Seite"));
echo(str("Rest Tiefe        ", rest_t, " mm für BMS und Kabel"));
echo(str("Höhe belegt       ", hoehe_belegt, " mm"));
echo(str("Höhe Reserve      ", hoehe_reserve, " mm"));
echo(str("Trennfuge bei     ", fuge_z, " mm"));
echo(str("Segment unten     ", seg_u_h, " mm hoch"));
echo(str("Segment oben      ", seg_o_h, " mm hoch"));

assert(spiel_b > 2 * druck_tol,
  "Spiel in der Breite kleiner als die doppelte Drucktoleranz.");
assert(hoehe_reserve > 0,
  "Höhenbilanz überschritten.");
assert(wand_stirn >= eckradius + wand_min,
  "Stirnwand zu dünn: die Zwickelnut würde sie durchbrechen.");
assert(seg_u_h <= 340 && seg_o_h <= 340,
  "Ein Segment überschreitet die Bauhöhe des H2S von 340 mm.");
assert(platte_vorn_y + endplatte_dicke <= bauraum_t - wand_stirn,
  "Die vordere Endplatte passt nicht in die Tiefe.");

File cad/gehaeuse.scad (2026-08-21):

// SPDX-License-Identifier: CERN-OHL-S-2.0
//
// Copyright 2026 Christoph Steinbeck
//
// This source describes Open Hardware and is licensed under the CERN-OHL-S v2.
// You may redistribute and modify this source and make products using it under
// the terms of the CERN-OHL-S v2 (https://ohwr.org/cern_ohl_s_v2.txt).
// This source is distributed WITHOUT ANY EXPRESS OR IMPLIED WARRANTY, INCLUDING
// OF MERCHANTABILITY, SATISFACTORY QUALITY AND FITNESS FOR A PARTICULAR PURPOSE.
// Please see the CERN-OHL-S v2 for applicable conditions.

// ═══════════════════════════════════════════════════════════════════
//  Zellblock 16 — Gehäusesegmente
//
//  Zwei Segmente, weil 425 mm nicht in die 340 mm Bauhöhe des H2S
//  passen. Die Trennfuge liegt auf der Oberkante der Zwischenplatte:
//  dort ist ohnehin eine steife Ebene, und keine Zelle wird geschnitten.
//
//  Das Gehäuse trägt nichts. Die Zellverspannung von 6–10 kN je Etage
//  läuft ausschließlich über die Aluplatten und die waagerechten
//  Zugstangen. Hier geht es um Hülle, Führung im Schacht und Isolierung
//  gegen den Rahmen.
//
//  Verbunden werden die Segmente nicht miteinander, sondern jeweils mit
//  der durchgehenden hinteren Aluplatte: Sie ist 400 mm hoch, überbrückt
//  die Fuge und hält beide Hälften. Die Zentrierzapfen sorgen nur für
//  Flucht beim Zusammensetzen.
//
//  Ausgabe:
//    openscad -D 'teil="unten"' -o segment_unten.stl gehaeuse.scad
//    openscad -D 'teil="oben"'  -o segment_oben.stl  gehaeuse.scad
// ═══════════════════════════════════════════════════════════════════

include <parameter.scad>
use <kontur.scad>

teil = "unten";   // "unten" | "oben" | "beide"

// ── Zentrierzapfen ─────────────────────────────────────────────────
// In den Stirnwänden, wo mit 8 mm genug Material sitzt. In den 2,5 mm
// dünnen Seitenwänden wäre kein Platz.
zapfen_x = [ fach_b/2, bauraum_b/2, bauraum_b - fach_b/2 ];

module zapfen_positionen() {
    for (x = zapfen_x)
        for (y = [ wand_stirn/2, bauraum_t - wand_stirn/2 ])
            translate([x, y, 0])
                children();
}

module zapfen(spiel = 0) {
    translate([-zapfen_l/2 - spiel, -zapfen_b/2 - spiel, 0])
        cube([zapfen_l + 2*spiel, zapfen_b + 2*spiel, zapfen_h + spiel]);
}

// ── Befestigung an der hinteren Aluplatte ──────────────────────────
// Durch die Rückwand in Gewinde im 8 mm starken Aluminium. Damit hängen
// beide Segmente an derselben Platte und sind darüber verbunden.
module plattenschrauben(z_von, z_bis) {
    n  = schrauben_je_segment;
    dz = (z_bis - z_von) / (n + 1);
    for (i = [1 : n])
        for (x = [ bauraum_b/2 - 90, bauraum_b/2 + 90 ])
            translate([x, wand_stirn + 1, z_von + i*dz])
                rotate([90, 0, 0]) {
                    cylinder(d = schraube_d, h = wand_stirn + 2);
                    translate([0, 0, wand_stirn - 2.2])
                        cylinder(d1 = schraube_d, d2 = schraube_kopf, h = 2.4);
                }
}

// ── Grundkörper eines Segments ─────────────────────────────────────
module segment_rohling(h) {
    linear_extrude(height = h) wand_2d();
}

// ── Unterteil ──────────────────────────────────────────────────────
module segment_unten() {
    difference() {
        union() {
            // Boden über die volle Fläche: Er leitet die 43 kg flächig
            // in den Schachtboden ein. Deshalb durchgehend, nicht als
            // Ring — konstruktion.md §6.
            linear_extrude(height = boden_dicke) aussen_2d();
            segment_rohling(seg_u_h);
            plattenfuss();
            translate([0, 0, seg_u_h]) zapfen_positionen() zapfen();
        }
        // Kabeldurchführungen an den Fachmitten, wo die Originalkontakte
        // saßen. Deren Öffnungen im Schachtboden werden weiterverwendet.
        for (x = zapfen_x)
            translate([x, bauraum_t - wand_stirn - 26, -1])
                cylinder(d = kabel_d, h = boden_dicke + 2);
        plattenschrauben(boden_dicke + 20, seg_u_h - 12);
    }
}

// Keine Bodenverrippung: Der Boden liegt vollflächig auf dem
// Schachtboden auf und kann sich deshalb gar nicht durchbiegen. Er muss
// die Last nur durchleiten, nicht auf Biegung aufnehmen. Rippen würden
// hier nur die Zellen anheben, statt auf dem Boden stehen zu lassen.

// Zwei flache Nasen, auf denen die vordere Aluplatte beim Einsetzen
// steht, bevor die Zugstangen sie fixieren.
module plattenfuss() {
    for (x = [ bauraum_b/2 - 70, bauraum_b/2 + 70 ])
        translate([x - 14, platte_vorn_y - 1, boden_dicke])
            cube([28, endplatte_dicke + 2, 3]);
}

// ── Oberteil ───────────────────────────────────────────────────────
module segment_oben() {
    difference() {
        segment_rohling(seg_o_h);
        // Gegentaschen für die Zentrierzapfen
        translate([0, 0, -0.1]) zapfen_positionen() zapfen(zapfen_spiel);
        plattenschrauben(12, seg_o_h - 30);
        lueftung();
    }
    deckelauflage();
}

// Entlüftung im Kopfraum. Die Zellen geben ihre Wärme fast nur über
// Pole und Böden ab (1–2 W/(m·K) durch die Dicke gegen 18–24 in der
// Ebene), deshalb muss die Luft oben zirkulieren können.
module lueftung() {
    // Nur im Kopfraum über der oberen Zellebene, und mit Abstand zur
    // Deckelauflage — sonst wären es oben offene Nuten statt Schlitze.
    zellen_oben = seg_o_h - kopfraum;
    z0 = zellen_oben + 2;
    h  = kopfraum - deckel_dicke - 5;
    for (i = [0 : lueftung_n - 1]) {
        x = bauraum_b * (i + 0.5) / lueftung_n;
        for (y = [-1, bauraum_t - wand_stirn - 1])
            translate([x - lueftung_b/2, y, z0])
                cube([lueftung_b, wand_stirn + 2, h]);
    }
    echo(str("Lüftungsquerschnitt ",
             2 * lueftung_n * lueftung_b * h, " mm²"));
}

// Umlaufende Stufe innen, auf der der Deckel aufliegt und bündig
// abschließt. Als aufgesetzte Stufe, nicht als eingefräster Falz: Ein
// Falz würde die 2,5 mm dünnen Seitenwände auf unter 1 mm reduzieren.
// Im Kopfraum ist dafür Platz, weil dort keine Zellen mehr stehen.
module deckelauflage() {
    z0 = seg_o_h - deckel_dicke - auflage_b;
    difference() {
        translate([0, 0, z0])
            linear_extrude(height = auflage_b) innen_2d();
        translate([0, 0, z0 - 0.1])
            linear_extrude(height = auflage_b + 0.2)
                offset(delta = -auflage_b) innen_2d();
    }
}

// ── Ausgabe ────────────────────────────────────────────────────────
if (teil == "unten")      segment_unten();
else if (teil == "oben")  segment_oben();
else {
    segment_unten();
    translate([0, bauraum_t + 40, 0]) segment_oben();
}

echo(str("Segment unten  eingebaut ", seg_u_h,
         " mm, Druckhöhe ", seg_u_h + zapfen_h, " mm (mit Zapfen)"));
echo(str("Segment oben   eingebaut ", seg_o_h, " mm"));
assert(seg_u_h + zapfen_h <= 340, "Unterteil mit Zapfen über 340 mm Bauhöhe.");

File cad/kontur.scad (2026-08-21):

// SPDX-License-Identifier: CERN-OHL-S-2.0
//
// Copyright 2026 Christoph Steinbeck
//
// This source describes Open Hardware and is licensed under the CERN-OHL-S v2.
// You may redistribute and modify this source and make products using it under
// the terms of the CERN-OHL-S v2 (https://ohwr.org/cern_ohl_s_v2.txt).
// This source is distributed WITHOUT ANY EXPRESS OR IMPLIED WARRANTY, INCLUDING
// OF MERCHANTABILITY, SATISFACTORY QUALITY AND FITNESS FOR A PARTICULAR PURPOSE.
// Please see the CERN-OHL-S v2 for applicable conditions.

// ═══════════════════════════════════════════════════════════════════
//  Zellblock 16 — Konturen
//
//  Die Außenkontur ist die Vereinigungsmenge dreier
//  Kraftpaket-Grundrisse. Sie passt damit per Konstruktion in den
//  Schacht, und die Einbuchtungen an den ehemaligen Trennebenen
//  nehmen die Führungsrippen auf, ohne dass am Fahrzeug gefräst wird.
// ═══════════════════════════════════════════════════════════════════

include <parameter.scad>

// Ein Originalfach: Rechteck fach_b × bauraum_t mit gerundeten
// Vertikalkanten.
module fach_2d(r = eckradius) {
    translate([r, r])
        offset(r = r)
            square([fach_b - 2*r, bauraum_t - 2*r]);
}

// Außenkontur: drei Fächer nebeneinander.
//
// Wo zwei Fächer aneinanderstoßen, treffen sich an Vorder- und
// Rückkante zwei Viertelrundungen. Dazwischen bleibt eine linsenförmige
// Einbuchtung von 2·r Breite und r Tiefe stehen — das ist die
// Zwickelnut, in die die Führungsrippe greift. Sie entsteht von selbst
// aus der Vereinigung; sie wird nicht konstruiert.
module aussen_2d() {
    union()
        for (i = [0 : 2])
            translate([i * fach_b, 0])
                fach_2d();
}

// Innenkontur: schlichtes Rechteck. Die Zwickel gehören nach außen,
// innen soll der Raum durchgehend und glatt sein.
module innen_2d(r = 3) {
    translate([wand_seite + r, wand_stirn + r])
        offset(r = r)
            square([innen_b - 2*r, innen_t - 2*r]);
}

// Wandquerschnitt als Ring.
module wand_2d() {
    difference() {
        aussen_2d();
        innen_2d();
    }
}

// Grundriss einer Zellebene, für Passungsprüfungen und spätere Teile.
// Der Zellblock wird in der Breite mittig gesetzt, in der Tiefe an die
// hintere Endplatte geschoben.
module zellen_2d(tol = 0) {
    x0 = (bauraum_b - zellblock_b) / 2;
    y0 = wand_stirn + endplatte_dicke;
    for (i = [0 : zellen_je_reihe - 1])
        for (j = [0 : zellen_je_stapel - 1])
            translate([x0 + i * zelle_l - tol,
                       y0 + j * zelle_t - tol])
                square([zelle_l + 2*tol, zelle_t + 2*tol]);
}

// Polpositionen einer Zellebene. Jede Zelle trägt zwei Pole im Abstand
// zelle_polabst, mittig auf ihrer Oberseite. Daraus ergibt sich ein
// Raster von 4 Spalten × 4 Reihen = 16 Polen je Etage.
module pol_positionen() {
    x0 = (bauraum_b - zellblock_b) / 2;
    y0 = wand_stirn + endplatte_dicke;
    for (i = [0 : zellen_je_reihe - 1])
        for (j = [0 : zellen_je_stapel - 1])
            for (s = [-1, 1])
                translate([x0 + i*zelle_l + zelle_l/2 + s*zelle_polabst/2,
                           y0 + j*zelle_t + zelle_t/2])
                    children();
}

// Die x-Lagen der vier Polspalten, für die Busbarkanäle.
function pol_spalten() = [
    for (i = [0 : zellen_je_reihe - 1], s = [-1, 1])
        (bauraum_b - zellblock_b)/2 + i*zelle_l + zelle_l/2
        + s*zelle_polabst/2
];

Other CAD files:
cad/montage.scad
cad/platten.scad
cad/testring.scad

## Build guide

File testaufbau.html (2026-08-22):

Zellblock 16 · Erprobung vor dem ersten Eingriff

# Testaufbau16 Zellen außerhalb des Fahrzeugs · ohne Gehäuse

Zeichnungs-Nr. ZB-16-004
Blatt 1 / 1 · Maße in mm
Stand 22.08.2026 · Rev. A

### Draufsicht — zwei Blöcke zu acht Zellen

### Seitenansicht — Verspannung

## Verspannen, auch im Test

Die Zellen atmen bei jedem Ladezyklus, nicht erst über Jahre. Laut Datenblatt steigt die Kraft bei starrer Einspannung schon an einer neuen Zelle um bis zu 3 kN.

Mit 3–4 kN Vorspannung landet man damit bei 6–7 kN — unter der Schadensgrenze von 9 kN, aber ohne viel Luft. Mit Tellerfedern bleibt es bei rund 5 kN. Sie werden ohnehin gekauft; sie hier wegzulassen spart nichts.

## Was der Test klärt

1. Gibt der Controller frei? Datenpin-Brücke und CAN-Modul
2. Läuft der Motor am aufgebockten Rad?
3. Verträgt er 58,4 V? Nur 1,6 V Abstand zur 60-V-Grenze
4. Wie verhält sich das BMS unter Last?
5. Lädt und balanciert das Ladegerät sauber?

## Stückliste Testaufbau

Teil | Stk
Zellen EVE LF105 | 16
Holzplatte 18 mm, 300 × 220 | 4
Gewindestange M8, 400 mm | 8
Tellerfedern | 48
Muttern M8, Scheiben | je 16
Busbars kurz | 12
Verbinder lang, 63 mm | 2
Blockverbinder als Kabel | 1
BMS, Sicherung, Trennschalter | je 1

## Maße

Block, 8 Zellen | 291 × 130
Beide Blöcke | 291 × 261
Höhe mit Polen | 200,5
Masse Zellen | 31,7 kg
Spannung | 51,2 V

Der Aufbau bildet die spätere Verschaltung eins zu eins ab — zwei Blöcke zu acht, nur nebeneinander statt in zwei Etagen. Grundlage: grundlagen.md §8.4 · verschaltung.html

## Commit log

2026-08-20 Faktenbasis aus Benutzerhandbuch erarbeitet
    Wertet das Benutzerhandbuch des Kumpan 54 ignite aus und stellt die
    Projektgrundlage auf belegte Herstellerangaben um.
    Zentrale Belege:
    - 14S bestaetigt ueber Ladegeraet PBI48-8 mit 59 V (= 4,214 V/Zelle,
    NMC-Ladeschluss). Damit ist LFP ausgeschlossen, 13S und 15S ebenso.
    - Motor-Spitzenleistung 7000 W belegt -> Auslegungsstrom 167 A statt der
    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
2026-08-20 Kostenabschaetzung und geklaerten Lastpfad ergaenzt
    Lastpfad: Der Akku steht auf dem Schachtboden auf, haengt nicht an
    Auflagen. Die Zellmasse wird also ueber den Gehaeuseboden abgetragen -
    bei ~36 kg das Vierfache eines Originalakkus.
    Kostenabschaetzung mit drei Beschaffungswegen fuer die Zellen, weil sich
    bei der Recherche zeigte, dass prismatische NMC-Zellen im europaeischen
    DIY-Handel praktisch nicht erhaeltlich sind (Markt ist LFP-dominiert).
    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
2026-08-20 LFP von verworfen zu dokumentierter Rueckfalloption
    Das Ausschlussargument 'Ladegeraet liefert 59 V' traegt nicht mehr, da
    das Seriengeraet ohnehin ersetzt wird (6 A = 15 h Ladezeit).
    Neu gefunden: Das im LFP-Markt normierte Hoehenmass von ~200 mm
    kollidiert mit den 410 mm Bauhoehe. Zwei Etagen ergeben 401 mm, eine
    Etage fasst nur 10-12 der benoetigten 16 Zellen. Fuer LFP ist zwingend
    ein flacheres Zellformat noetig.
    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
2026-08-20 Raffler-Auskunft, Zellmechanik und Hoehenmessung M13
    Raffler (Entwickler des CAN-Moduls) hat geantwortet: Das Modul
    interagiert nicht mit dem Akku, es taeuscht dessen Anwesenheit nur vor.
    Damit ist das SoC-Argument gegen LFP gegenstandslos - es leitet keinen
    Ladestand aus der Spannung ab. 16S LFP haelt er zu 99 Prozent fuer
    problemlos nutzbar. Neue harte Grenze: Motorcontroller max. 60 V.
    Folge, die bewusst hinzunehmen ist: Nach dem Umbau zeigt der Roller
    keinen echten Ladestand mehr an. Der SoC kommt aus der BMS-App.
    Aus dem EVE-Datenblatt LF105 zwei konstruktionsbestimmende Befunde:
    - Prismatische Zellen brauchen 3-5 kN Vorspannung und entwickeln am
    Lebensende bis 30 kN Ausdehnungskraf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
2026-08-20 Einbaulage geklaert: stehend, Pole oben
    Extern recherchiert, was im EVE-Datenblatt fehlte. Herstelleruebergreifend
    gilt: Pole oben ist die empfohlene Lage, kopfueber ist verboten (Elektrolyt
    setzt das Ventil ausser Funktion), liegend auf der Kante wird nicht
    empfohlen.
    Unabhaengig davon scheitern alle liegenden Varianten geometrisch: Die
    200,5-mm-Achse traegt die Pole und passt bequem nur in die 270-mm-Breite.
    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
2026-08-21 Blaupause: Projektname Zellblock 16
    Der Eigenbau traegt nicht mehr die Marke des OEM-Akkus, um Konflikte mit
    dem Aufkaeufer der Kumpan-Reste zu vermeiden. Zeichnungsnummer und
    Schriftfeld entsprechend angepasst, 'Ersetzt: 3 x OEM-Wechselakku'.
    Zuvor die Tiefenstaffelung korrigiert: Beide Aluplatten wurden zuletzt
    gerendert und lagen deshalb vor dem Paket. Jetzt werden Zugstangen und
    hintere Endplatte vor dem Stapel gezeichnet, die vordere danach. Die
    Zugstangen sind ausserdem nach hinten herausgezogen statt quer durch den
    Stapel gefuehrt.
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2026-08-21 Parametrisches Modell und Testring T-01
    Fundament in cad/: parameter.scad haelt alle Masse an einer Stelle und
    prueft sie per assert, kontur.scad die Konturen, testring.scad das
    Musterstueck.
    Die Aussenkontur entsteht als Vereinigung dreier Originalfach-Grundrisse.
    Die vier Zwickelnuten fuer die Fuehrungsrippen bilden sich dabei von
    selbst, weil an jeder Trennebene zwei Viertelrundungen aufeinandertreffen.
    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
    [kontur.scad, parameter.scad, testring.scad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]
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2026-08-21 Vergleichspreis korrigiert: Originalakku kostet 1.400 EUR pro Stueck
    Die bisherige Annahme von ~700 EUR stammte aus JJacs Forenbeitrag und ist
    ueberholt. Die Packs sind weiterhin erhaeltlich, kosten aber das Doppelte;
    drei Stueck also 4.200 statt 2.100 EUR.
    Damit dreht sich das Hauptargument: Nicht die fehlende Verfuegbarkeit
    spricht fuer den Eigenbau, sondern der Preis. Ersparnis rund 2.700 EUR
    oder 64 Prozent, mit Werkzeug und Abnahme immer noch ueber 1.800 EUR.
    Je kWh: 970 EUR beim Original gegen 282 EUR beim Eigenbau. Oder anders:
    Ein einzelner Originalpack kostet 1.400 EUR fuer 1,44 kWh, der komplette
    Eigenbau 1.515 EUR fuer 5,38 kWh.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
2026-08-21 Gehaeusesegmente
    Zwei Segmente, Trennfuge auf der Oberkante der Zwischenplatte bei
    213,5 mm: dort ist ohnehin eine steife Ebene und keine Zelle wird
    geschnitten. Unterteil 213,5 mm eingebaut (221,5 Druckhoehe mit Zapfen),
    Oberteil 207,5 mm. Zusammen 2,7 kg Material.
    Die Segmente werden nicht miteinander verbunden, sondern jeweils an die
    durchgehende hintere Aluplatte geschraubt, die mit 400 mm ueber die Fuge
    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
    [gehaeuse.scad, parameter.scad, segment_oben.stl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]
2026-08-21 Zwischenplatte und Deckel, Druckzeit aus dem Testring hochgerechnet
    Die Zwischenplatte nimmt die ueberstehenden Pole der unteren Etage samt
    Busbars in vier Laengskanaelen auf, die unter den Polspalten liegen.
    Dazwischen bleiben 35-39 mm massives Material, ueber den Kanaelen tragen
    3 mm; beides per assert gesichert. Genau dieser Kunstgriff haelt die
    Hoehenbilanz bei 425 statt 436 mm.
    Der Deckel traegt die eigentliche Lueftung mit 3.570 mm2 gegen 216 mm2
    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
    [deckel.stl, gehaeuse.scad, kontur.scad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]
2026-08-21 Druckzeit korrigiert: 32 h statt 116 h
    Der Testring braucht im Standardprofil 2h10 statt 7h45, also 97 statt
    27 cm3/h. Das ganze Gehaeuse kommt damit auf rund 32 Stunden, verteilt
    auf vier Einzeldrucke mit maximal 15 h.
    Damit entfallen beide Empfehlungen aus dem vorigen Commit: Die
    0,6-mm-Duese wird nicht gebraucht, und duennere Stirnwaende mit lokalen
    Verdickungen an den Zwickelnuten lohnen nicht - sie haetten sechs Stunden
    und 0,7 kg gespart und dafuer eine zusaetzliche Fehlerquelle eingefuehrt.
2026-08-21 Projektdokumentation und Montagemodell
    README als Einstieg mit Kenndaten, Aufbauprinzip, Kostenvergleich und
    Projektstand. Dazu montage.scad, das den Gesamtaufbau zeigt, und daraus
    gerenderte Bilder in docs/img.
    Das Benutzerhandbuch wurde aus der Historie entfernt (git-filter-repo)
    und per .gitignore ausgeschlossen: Es ist urheberrechtlich geschuetztes
    Herstellermaterial und wird nur zitiert, nicht weitergegeben. Die
    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
    [montage.scad]
2026-08-21 STL-Dateien nicht mehr versionieren
    Sie waren getrackt, bevor die .gitignore-Regel dazukam. Erzeugnisse
    gehoeren nicht ins Repo: Sie veralten bei jeder Parameteraenderung, ohne
    dass es auffaellt, und das Projekt ist gerade in Aenderung - der laufende
    Testdruck kann eine Masskorrektur ausloesen, die alle vier Teile betrifft.
    Einzige Quelle der Wahrheit sind die .scad-Dateien. Der Bauaufruf fuer
    alle Teile steht jetzt in cad/README.md.
    [deckel.stl, segment_oben.stl, segment_unten.stl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]
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2026-08-21 Konsistenz: alle Dokumente auf 16S LFP gebracht
    grundlagen.md behauptete an zwanzig Stellen noch NMC als Primaerpfad.
    Abschnitt 3 ist jetzt sauber getrennt in 3.0 (Befund am Original: 14S NMC,
    belegt ueber das Ladegeraet) und 3.1 (Entscheidung fuer den Ersatzpack:
    16S LFP, mit der Begruendung warum alle drei fruehreren Gegenargumente
    entfielen). NMC steht nun in der Verworfen-Tabelle.
    Weitere korrigierte Inkonsistenzen:
    - Stroeme in Paragraph 4 waren fuer 14S NMC gerechnet (167 A bei 42 V).
    Neu fuer 16S LFP: 175 A bei 40 V, Auslegung unveraendert 180 A.
    - Kapazitaet und Reichweite: 5,18 kWh und 96 km stammten aus der
    NMC-Rechnung. Richtig sind 5,38 kWh und ~100 km - auch in README und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
2026-08-21 Lizenz CERN-OHL-S 2.0 und Projektseite
    CERN Open Hardware Licence v2, Strongly Reciprocal. Sie deckt anders als
    Software- oder Textlizenzen ausdruecklich Konstruktionsunterlagen,
    CAD-Dateien und daraus gefertigte Produkte ab. Reziprok: Wer den Entwurf
    aendert und weitergibt, muss die Aenderungen offenlegen; wer nur fuer sich
    baut, hat keine Pflichten.
    Der von der Lizenz vorgeschriebene Vermerk steht in allen .scad-Dateien,
    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
    [gehaeuse.scad, kontur.scad, montage.scad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]
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2026-08-22 Verschaltung und Kabelfuehrung
    Zwei neue Zeichnungen: verschaltung.html zeigt eine Zellebene mit
    Busbars, Polaritaeten und Verschaltungsreihenfolge, verdrahtung.html den
    Stromlaufplan samt Schnitt durch den Kabelschacht.
    Beim Zeichnen der Verschaltung wurde klar, dass die Zellen abwechselnd um
    180 Grad gedreht werden muessen. Nur so liegen die zu verbindenden Pole
    uebereinander und die Busbars ueberbruecken bloss die Zellteilung von
    36,35 mm statt zusaetzlich den Polabstand von 67 mm. Sechs der sieben
    Busbars sind dadurch kurz und gleich, nur der Uebergang zwischen den
    Reihen misst 63,3 mm und wird in anderer Laenge gebraucht - das fehlt
    noch in der Einkaufsliste.
    Kabelfuehrung korrigiert: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
